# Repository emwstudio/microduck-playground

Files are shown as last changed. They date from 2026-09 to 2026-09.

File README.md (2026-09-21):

# Microduck Playground



Watercolor illustration of Microduck pumping on its swing

Reproducible reinforcement-learning experiments, policy demonstrations, and
printable hardware add-ons for
[Pollen Robotics' Microduck](https://github.com/pollen-robotics/microduck).

This is an independent experimental continuation of
[`pollen-robotics/microduck_rl`](https://github.com/pollen-robotics/microduck_rl),
not an official Pollen Robotics release. For the initial public release, all
playground-specific work is consolidated into one commit on top of upstream
commit [`d424a0c`](https://github.com/pollen-robotics/microduck_rl/commit/d424a0c899f6b33cbd3daeb279913134349c0b63),
preserving the original project history and attribution. Development after the
release uses ordinary commits. The upstream project can be added as a Git
remote when preparing focused contributions.

<br clear="right">

## Experiments

Animated previews play directly in the table. Click one—or use its explicit
full-video link—to open the complete silent MP4.

<table>
  <thead>
    <tr>
      <th>Experiment</th>
      <th>Preview</th>
      <th>Result and artifacts</th>
    </tr>
  </thead>
  <tbody>
    <tr>
      <td><strong>Tug-of-war</strong></td>
      <td>
        <a href="experiments/tug-of-war/media/preview.mp4">
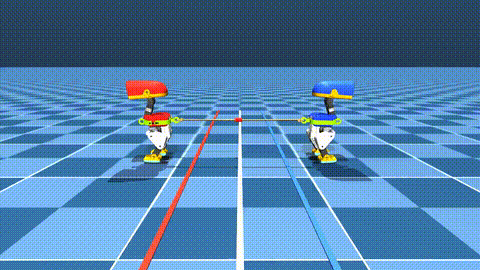
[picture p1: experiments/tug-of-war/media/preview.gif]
Two Microducks pulling a rope back-to-back, red ribbon at the rope midpoint
          
        </a>
      </td>
      <td>
        Two harness-collared ducks pull a real tension-only rope back-to-back;
        a red ribbon at the midpoint decides who wins when it crosses your
        line. Shipped bout: v16 fine-tuned steady-lean mirror, red wins at
        12.3 s, zero falls, near-zero rotation.<br>
        <a href="experiments/tug-of-war/media/preview.mp4">Full video</a> ·
        <a href="experiments/tug-of-war/README.md">Experiment and training</a>
      </td>
    </tr>
    <tr>
      <td><strong>Self-pumped swing</strong></td>
      <td>
        <a href="experiments/swing/media/alpha050_seed27.mp4">
          Animated preview of Microduck pumping itself on a swing
        </a>
      </td>
      <td>
        Starts still and reaches a 173.20° strict full span.<br>
        <a href="experiments/swing/media/alpha050_seed27.mp4">Full video</a> ·
        <a href="experiments/swing/README.md">Experiment</a> ·
        <a href="integrations/pollen-microduck/README.md">Runtime adapter</a> ·
        <a href="https://huggingface.co/HannesVonEssen/microduck-swing">ONNX on Hugging Face</a>
      </td>
    </tr>
    <tr>
      <td><strong>Blind basketball balance</strong></td>
      <td><a href="experiments/basketball/media/preview.mp4">Microduck balancing and moving on a basketball</a></td>
      <td>LSTM policy with no ball-state input: 97.01% survival over 60 seconds in 3,072 simulation trials. Experimental hardware-test candidate; hardware untested.<br>
      <a href="experiments/basketball/media/preview.mp4">Full video</a> ·
      <a href="experiments/basketball/README.md">Experiment and training</a> ·
      <a href="https://huggingface.co/HannesVonEssen/microduck-basketball">ONNX and checkpoint</a> ·
      <a href="https://github.com/pollen-robotics/microduck/pull/231">LSTM runtime PR</a></td>
    </tr>
    <tr>
      <td><strong>Fast running</strong></td>
      <td>
        <a href="experiments/running/media/preview.mp4">
          Animated preview of Microduck running on flat ground
        </a>
      </td>
      <td>
        Robustified iteration-12,195 simulation candidate: 1.651 m/s nominal,
        and 1.612 m/s under backlash plus disturbance stress.<br>
        <a href="experiments/running/media/preview.mp4">Full video</a> ·
        <a href="experiments/running/README.md">Experiment</a> ·
        <a href="https://huggingface.co/HannesVonEssen/microduck-running">ONNX on Hugging Face</a>
      </td>
    </tr>
    <tr>
      <td><strong>Stilt walking</strong></td>
      <td>
        <a href="experiments/stilts/media/preview.mp4">
          Animated preview of Microduck walking on green 10 cm stilts
        </a>
      </td>
      <td>
        Blend-0.50 policies for 10, 15, 20, 25, and 50 cm, plus
        1.0, 1.4, and 2.0 m simulation stilts (10 cm shown).<br>
        <a href="experiments/stilts/media/preview.mp4">Full video</a> ·
        <a href="experiments/stilts/README.md">Experiment</a> ·
        <a href="hardware/stilts/README.md">Hardware</a> ·
        <a href="https://huggingface.co/HannesVonEssen/microduck-stilts">Policies and videos</a>
      </td>
    </tr>
  <tr>
    <td><strong>Climbing</strong></td>
    <td><a href="experiments/desk-climb/media/preview.mp4">Cream Microduck climbing a modular ladder onto a desk and standing up</a></td>
    <td>Climb, land, recover.<br>
    <a href="experiments/desk-climb/README.md">Experiment and training</a> · <a href="hardware/ladder/README.md">Ladder and mounts</a> · <a href="https://huggingface.co/HannesVonEssen/microduck-climb">Models</a></td>
  </tr>
  </tbody>
</table>

Each preview is a direct simulation demonstration of the policy linked in its
row. Compact machine-readable evaluation records live beside each experiment.

## Hardware galleries

The retained swing seat keeps the battery centered without occupying the
head-and-leg pumping corridors. It includes compliant locating pads, a padded
strap, and a removable buckle. The source generators, printable millimetre
meshes, MuJoCo collision hulls, and clearance reports are under
[`hardware/swing-seat`](hardware/swing-seat/README.md).

<table>
  <tr>
    <td align="center">Retained swing seat, front view<br><sub>Front</sub></td>
    <td align="center">Retained swing seat, three-quarter view<br><sub>Three-quarter</sub></td>
    <td align="center">Retained swing seat, side view<br><sub>Side</sub></td>
  </tr>
</table>

The stilt system replaces the removable soles and preserves explicit tip
contact geometry. The gallery uses the demonstrated green 10 cm blend-0.50
configuration. Parametric generators and printable meshes are under
[`hardware/stilts`](hardware/stilts/README.md).

<table>
  <tr>
    <td align="center">Microduck green stilts, front view<br><sub>Front</sub></td>
    <td align="center">Microduck green stilts, three-quarter view<br><sub>Three-quarter</sub></td>
    <td align="center">Microduck green stilts, side view<br><sub>Side</sub></td>
    <td align="center">Green 3D-printed Microduck replacement sole and stilt prototype<br><sub>3D-printed prototype</sub></td>
  </tr>
</table>

The modular climbing ladder has pin-free stacking joints, a central spine, a
matching floor base and printed tightening screws for the table mounts.
Printable models, generators, assembly instructions and the full gallery are under
[`hardware/ladder`](hardware/ladder/README.md).

<table>
  <tr>
    <td align="center">Stackable ladder modules and friction-fit joints<br><sub>Stacking joints</sub></td>
    <td align="center">Modular ladder floor base<br><sub>Floor base</sub></td>
    <td align="center">Top module with threaded table mounts<br><sub>Table mounts</sub></td>
  </tr>
</table>

## Quick start

A CUDA GPU and [`uv`](https://docs.astral.sh/uv/) are recommended. Training
uses MuJoCo Warp through `mjlab`.

```bash
git clone https://github.com/Vottivott/microduck-playground
cd microduck-playground
uv sync

# Cheap configuration/training smoke test first.
uv run train Mjlab-SwingPump-MicroDuck \
  --env.scene.num-envs 64 \
  --agent.max-iterations 5

# Full swing training configuration.
uv run train Mjlab-SwingPump-MicroDuck \
  --env.scene.num-envs 4096
```

## Repository layout

```text
experiments/
  basketball/            blind LSTM policy, evaluation, continuation guide
  running/               clean policy preview and result summary
  stilts/                policy index, executed curriculum, continuation guide
  swing/                 selected checkpoints, evaluation, media, methodology
hardware/
  stilts/                parametric stilt generator and printable meshes
  swing-seat/            retained-seat generator, meshes, clearance reports
src/mjlab_microduck/     tasks, robot models, actuator model, rewards
scripts/                 evaluation, export, rendering, and selection tools
integrations/            policy-specific deployment adapters
tests/                   CPU configuration and invariant tests
docs/                    supporting research and training notes
```

## Scope and safety

These are simulation experiments, not hardware safety certifications. The
swing model simulates two elastic tension-only cords and randomized actuator
and sensor dynamics, but real cord knots, frame flex, textile contact, servo
temperature, and assembly tolerances remain. Extreme-height stilts require an
engineered load path and fall protection. Use a safety tether, current limits,
an emergency stop, a clear exclusion zone, and conservative incremental tests.

## Upstream and contributions

To compare against or prepare a focused pull request for Pollen's project:

```bash
git remote add upstream https://github.com/pollen-robotics/microduck_rl.git
git fetch upstream
```

## License

Software is licensed under Apache-2.0; see [`LICENSE`](LICENSE). As in the
upstream project, 3D hardware design files are licensed under Creative Commons
Attribution-NonCommercial-ShareAlike 4.0 International; see
[`LICENSE-HARDWARE`](LICENSE-HARDWARE). Third-party Microduck assets retain
their original attribution and terms. See [`NOTICE`](NOTICE) and the
hardware-specific READMEs.

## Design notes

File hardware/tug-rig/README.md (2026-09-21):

# Tug-of-war harness rig

Parametric, printable Microduck harness rig for the rope-tug demos: a
**standoff tow-pack** — a crowned back panel floating 28 mm behind the butt
shell on two standoff rails (jetpack-style), carrying the butt carabiner
(the pulled end), plus a chest carabiner (the pulling end), so the rope's
force path runs through the duck like a human puller's. Clearance is
validated with MuJoCo's own collision engine — see
[VALIDATION.md](VALIDATION.md).

<table>
  <tr>
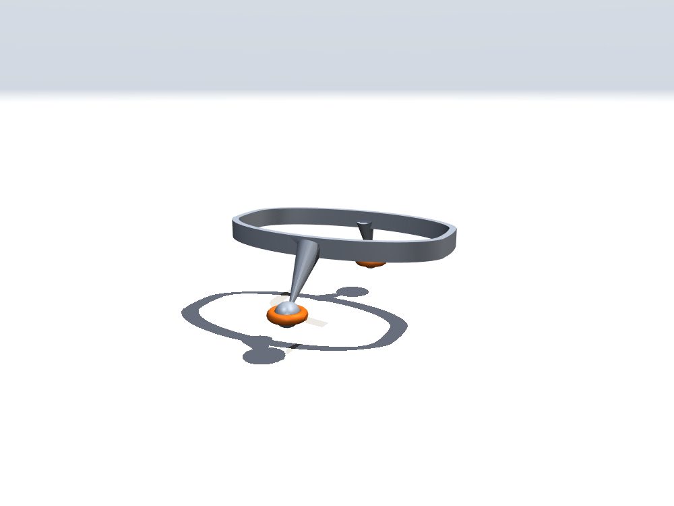
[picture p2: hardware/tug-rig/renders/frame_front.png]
Frame front view
    <td></td>
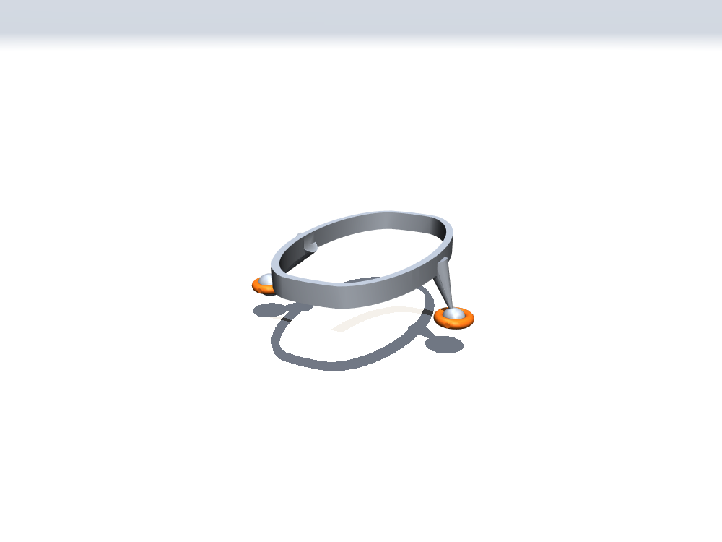
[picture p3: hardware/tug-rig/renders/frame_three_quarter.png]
Frame three-quarter view
    <td></td>
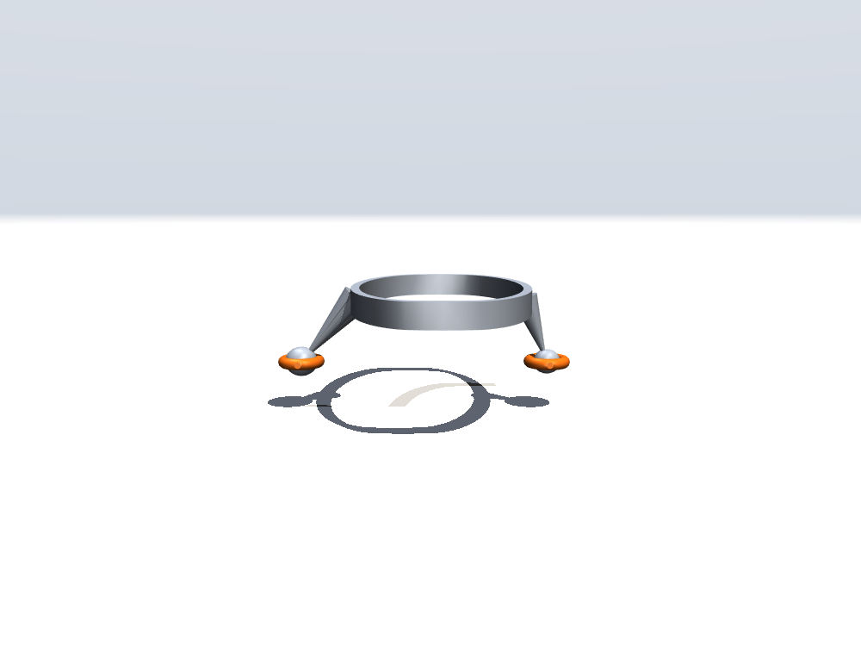
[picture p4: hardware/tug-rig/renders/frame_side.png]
Frame side view
    <td></td>
  </tr>
</table>

The tow-pack STL is a **single boolean-unioned solid** (panel + rails +
carabiner in one watertight mesh) — it prints as one piece. The sim uses the
same mesh with a single material; the carabiner's orange is a paint job, not
a separate part.

## Files

- `source/cad_rig.py` — waist-band variant (superseded by the saddle);
- `source/cad_towpack.py` — standoff tow-pack (current design): rounded
  panel + standoff rails + carabiner eye, watertight STL;
- `source/cad_saddle.py` — form-fitted butt saddle (superseded; lessons:
  a snug back cup inevitably overlaps the legs' fold-back swing cone);
- `source/verify_pack_contacts.py` — MuJoCo-native contact validation
  (per-joint sweeps + LHS + tug envelope, JSON report);
- `source/verify_saddle_clearance.py` — earlier trimesh/FCL validator
  (superseded by the MuJoCo-native one);
- `meshes/*_mm.stl` — millimetre-scale printable meshes;
- `../../src/mjlab_microduck/robot/microduck/assets/tug_frame.stl`,
  `tug_hook_carabiner.stl`, `tug_chest_carabiner.stl` — metre-scale MuJoCo
  visual meshes (water-tight, density-0 in the sim).

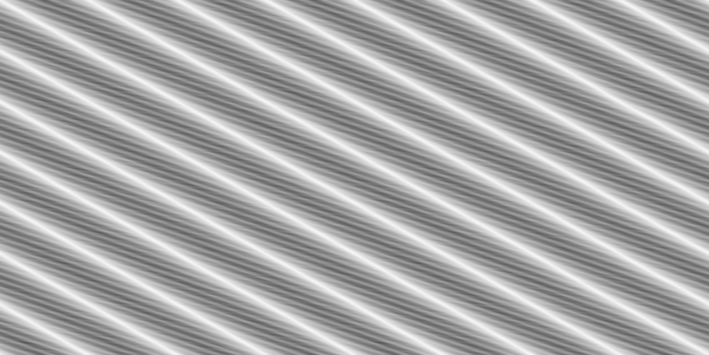
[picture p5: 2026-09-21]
src/mjlab_microduck/robot/microduck/assets/rope_hemp_roughness.png

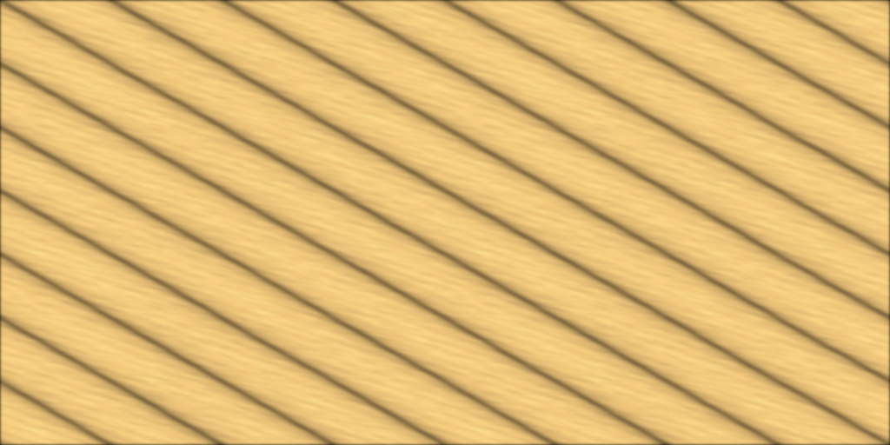
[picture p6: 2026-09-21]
src/mjlab_microduck/robot/microduck/assets/rope_hemp_color.png

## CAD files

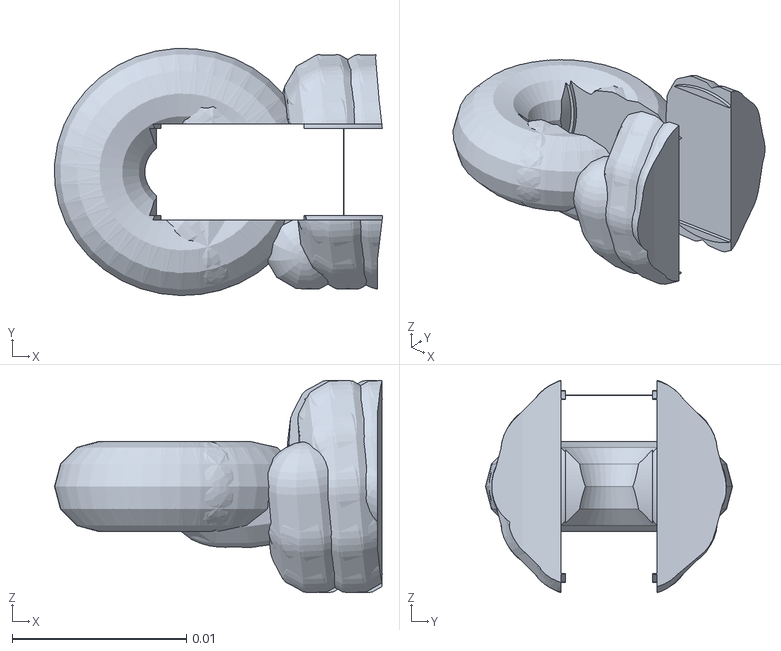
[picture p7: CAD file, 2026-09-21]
hardware/tug-rig/meshes/tug_knot_m.stl
0.0188 x 0.0142 x 0.0122

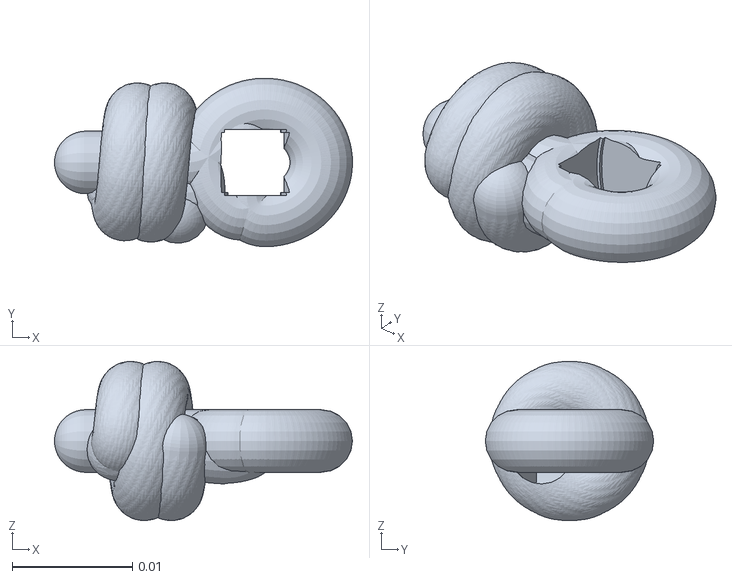
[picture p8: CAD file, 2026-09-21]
src/mjlab_microduck/robot/microduck/assets/tug_knot_mir.stl
0.0247 x 0.014 x 0.0132

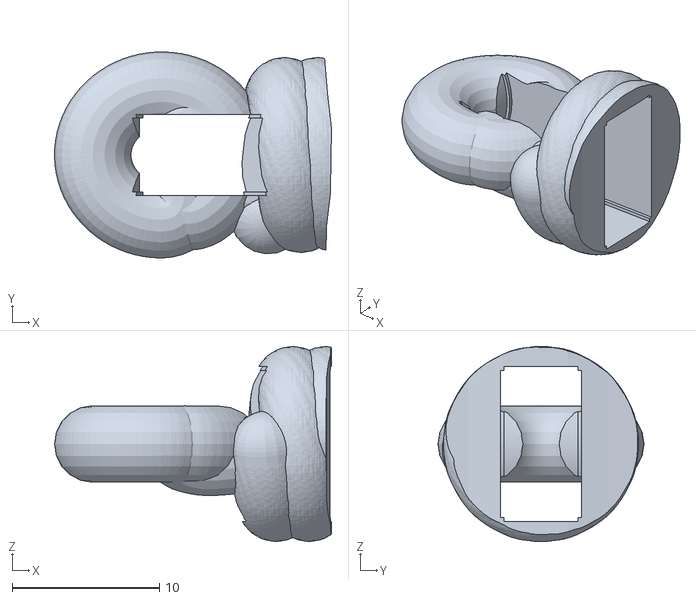
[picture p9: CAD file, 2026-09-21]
hardware/tug-rig/meshes/tug_knot_mm.stl
18.8 x 14.0 x 13.2

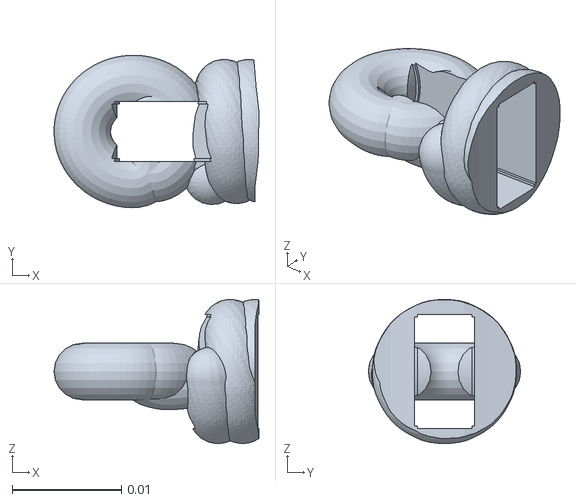
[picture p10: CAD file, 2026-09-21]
src/mjlab_microduck/robot/microduck/assets/tug_knot.stl
0.0188 x 0.014 x 0.0132

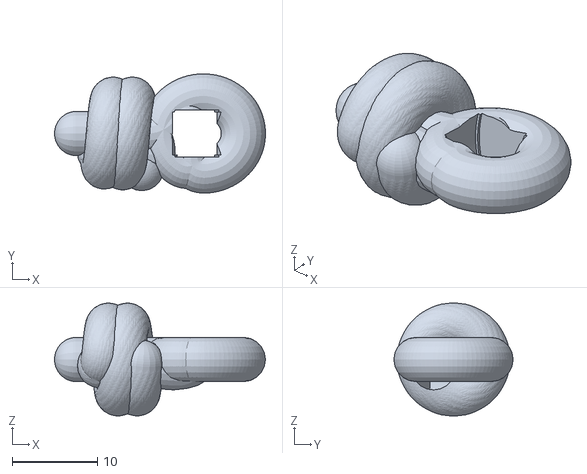
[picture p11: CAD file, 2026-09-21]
hardware/tug-rig/meshes/tug_knot_mir_mm.stl
24.7 x 14.0 x 13.2

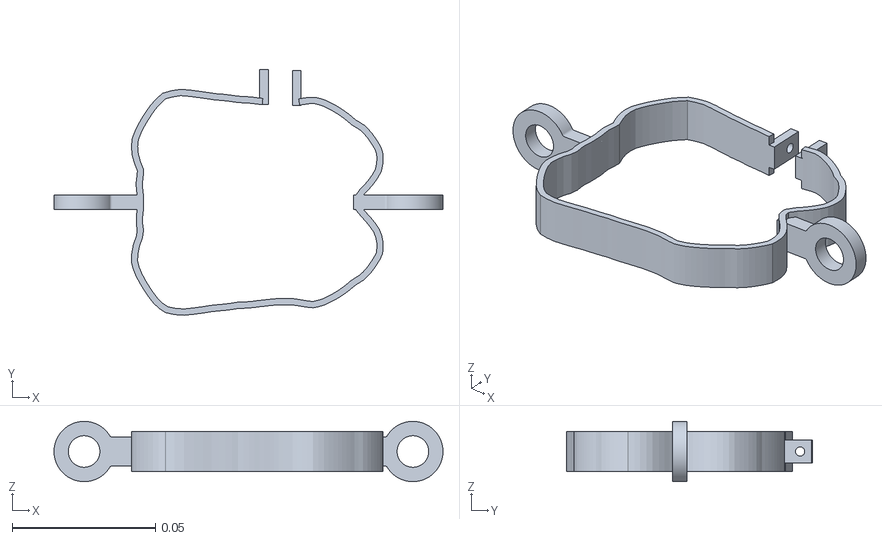
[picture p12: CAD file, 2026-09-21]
src/mjlab_microduck/robot/microduck/assets/tug_collar.stl
0.136 x 0.0856 x 0.021

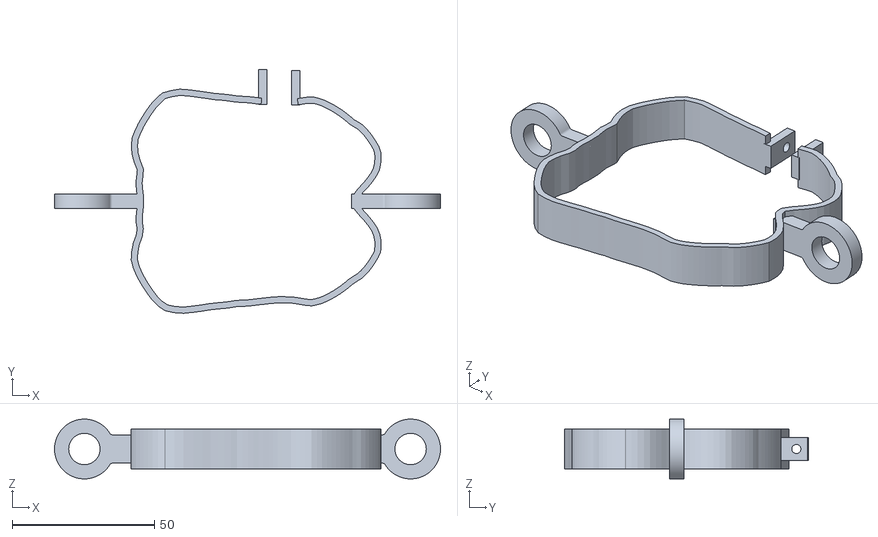
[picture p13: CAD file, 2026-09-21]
hardware/tug-rig/meshes/tug_collar_mm.stl
135.6 x 85.6 x 21.0

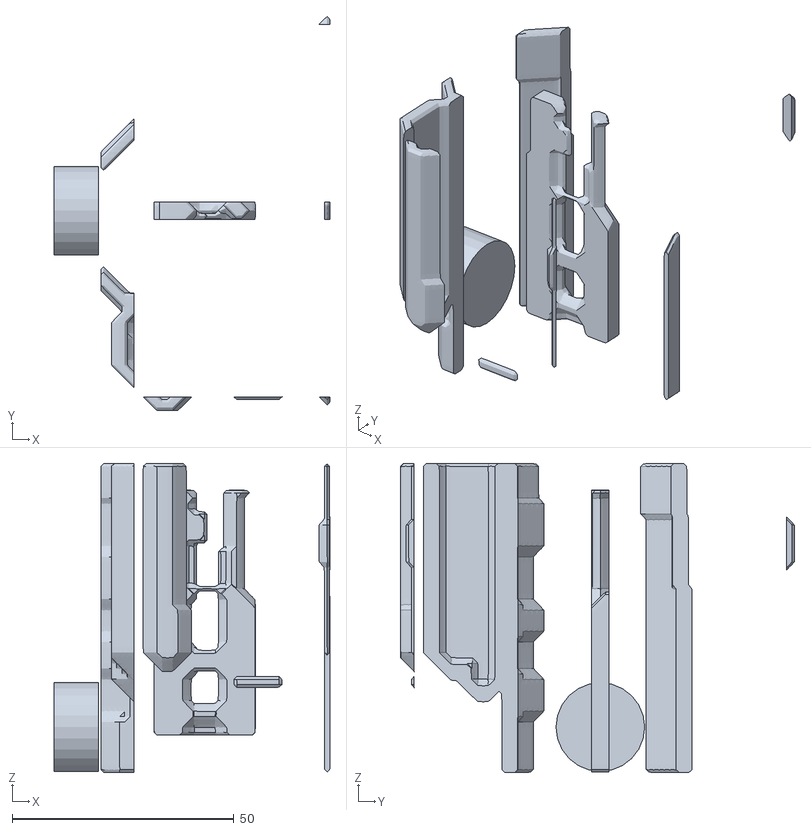
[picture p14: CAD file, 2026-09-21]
hardware/tug-rig/meshes/tug_saddle_mm.stl
62.2 x 88.8 x 69.7

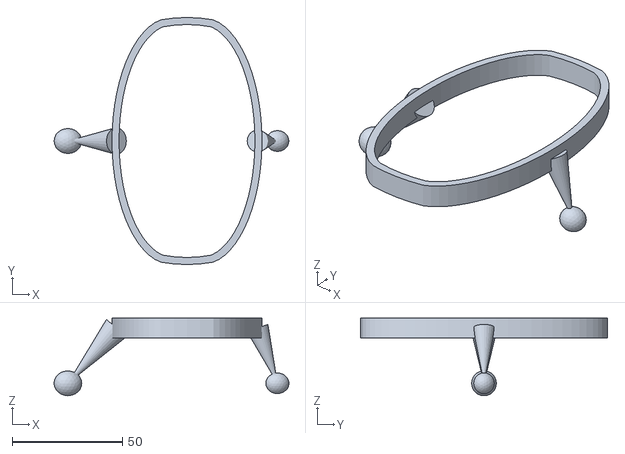
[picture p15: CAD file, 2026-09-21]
hardware/tug-rig/meshes/tug_frame_mm.stl
106.6 x 112.0 x 35.2

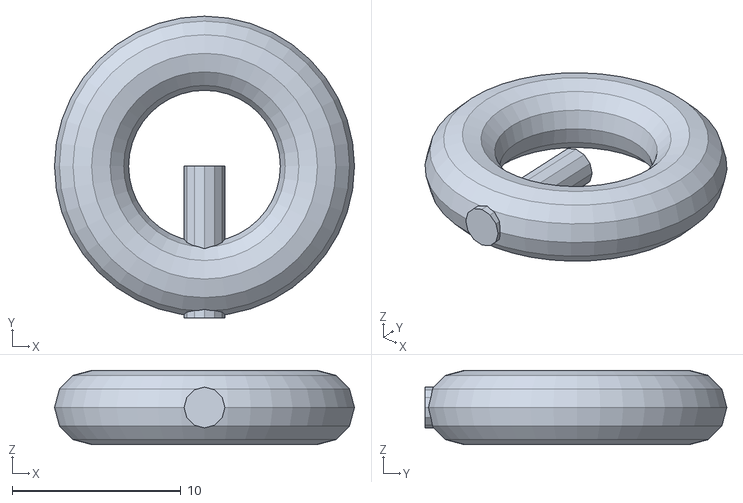
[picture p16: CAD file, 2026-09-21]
hardware/tug-rig/meshes/tug_chest_carabiner_mm.stl
17.8 x 17.9 x 4.40

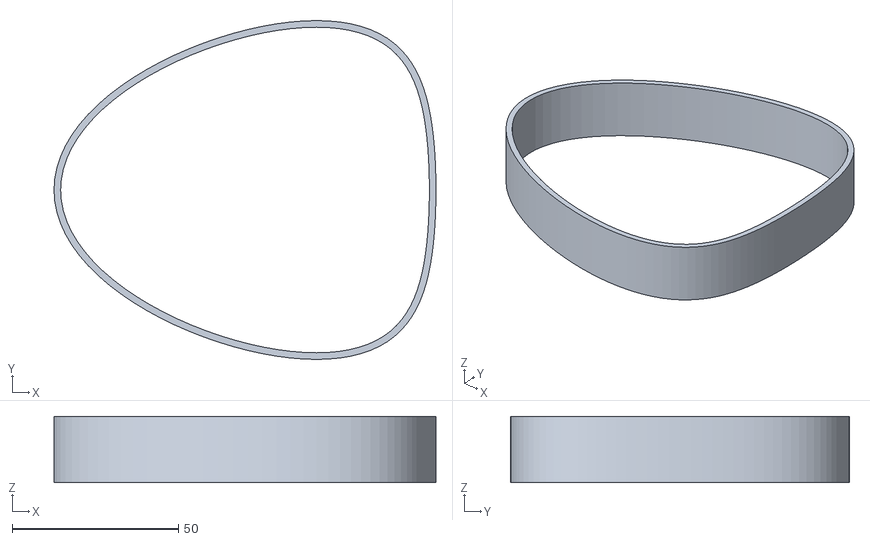
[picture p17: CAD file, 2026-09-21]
hardware/tug-rig/meshes/tug_strap_mm.stl
115.0 x 102.0 x 20.0

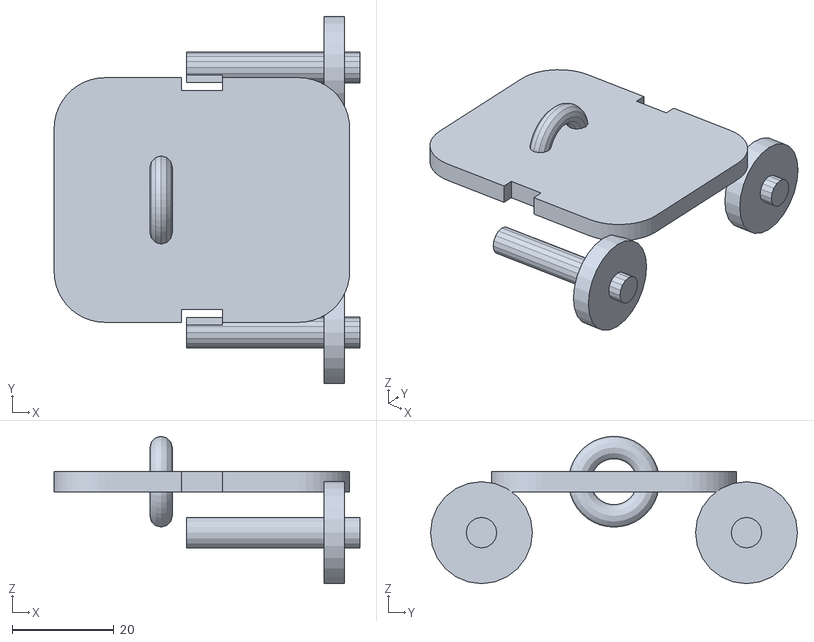
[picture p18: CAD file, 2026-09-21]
hardware/tug-rig/meshes/tug_towpack_mm.stl
60.0 x 72.0 x 28.9

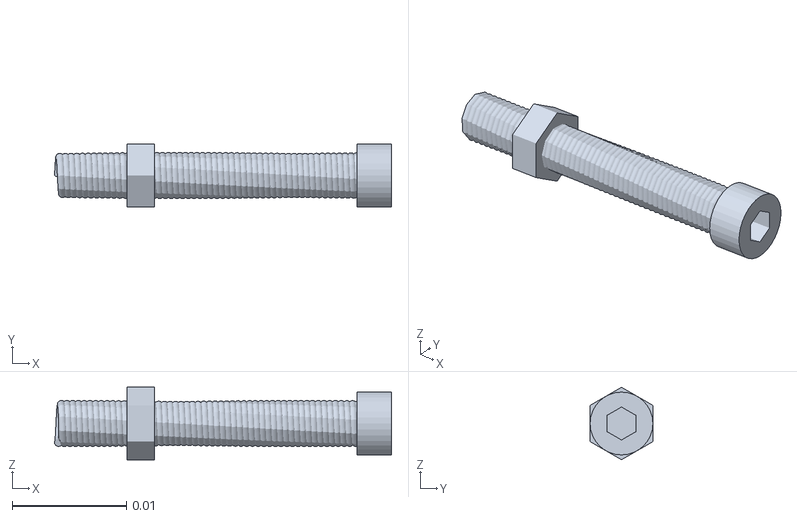
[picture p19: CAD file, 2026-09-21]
src/mjlab_microduck/robot/microduck/assets/tug_clamp_screw.stl
0.0295 x 0.0055 x 0.00635

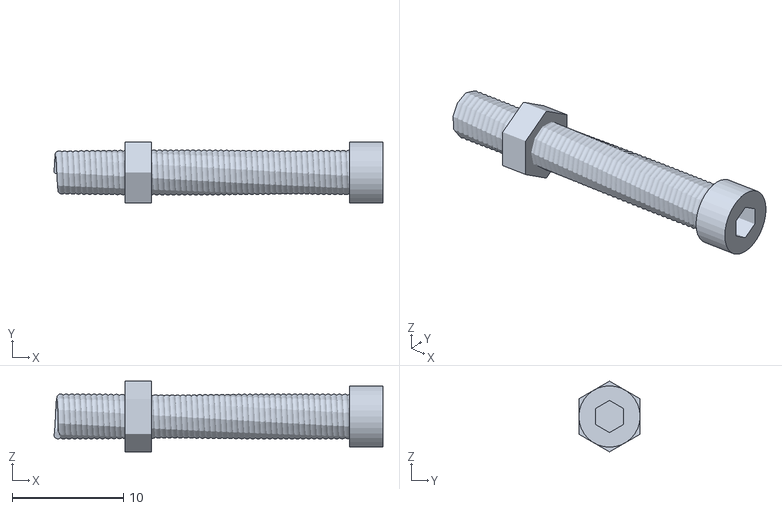
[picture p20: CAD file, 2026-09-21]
hardware/tug-rig/meshes/tug_clamp_screw_mm.stl
29.5 x 5.50 x 6.35

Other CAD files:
hardware/tug-rig/meshes/tug_knot_mir_m.stl
hardware/tug-rig/meshes/tug_carabiner_mm.stl
hardware/tug-rig/meshes/tug_hook_carabiner_mm.stl
src/mjlab_microduck/robot/microduck/assets/tug_knot.obj
src/mjlab_microduck/robot/microduck/assets/tug_knot_mir.obj

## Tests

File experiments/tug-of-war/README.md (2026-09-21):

# Tug-of-war — two ducks, one rope, real physics

Two Microducks (each wearing the printable harness collar with butt + chest
tow rings) pull a hemp rope back-to-back. A red ribbon marks the rope's
midpoint; dragging it past your coloured win line wins the bout.

Final shipped bout (`media/preview.mp4`, 4K in DuckEMW artifacts): the v16
fine-tuned steady-lean policy mirror, red wins at 12.3 s, zero falls, near
zero visible rotation.

## Reproduce

```bash
PYTHONPATH=src uv run scripts/tug_of_war.py \
  --n-per-team 1 --gap 0.55 \
  --policy-red  policies/tugchain_steady_v16_2250.onnx --red-kind  tug \
  --policy-blue policies/tugchain_steady_v16_2250.onnx --blue-kind tug \
  --rounds 1 --round-duration 25 --win-x 0.15 \
  --rope-stiffness 60 --rope-damping 2.0 --pretension 0.005 \
  --fatigue-start 6 --fatigue-floor 0.8 --fatigue-team red \
  --yaw-kp 0.8 --cam-track 0.3 --fps 50 \
  --out match.mp4
```

## Training tasks (registered in `tasks/__init__.py`)

| Task id | Layout |
|---|---|
| `Mjlab-Microduck-Tug-Steady/-Shuffle` | duck + harness drags a weighted sled (first recipe family) |
| `Mjlab-Microduck-TugChain-Steady/-Shuffle` | 1v1 duck chain, frozen v6 opponent |
| `Mjlab-Microduck-TugChain3-Steady/-Shuffle` | 3v3 chain, learner = middle duck, 5 frozen ducks |
| `Mjlab-Microduck-TugChain3S-Steady/-Shuffle` | 3v3 chain, all 6 ducks live learners (shared policy) |
| `Mjlab-Microduck-TugChainF-Steady/-Shuffle` | face-to-face variant (chest-ring rope, backward pull) |

## Key mechanisms (all measured, none guessed)

- **Real rope**: tension-only dead-band cord (stiffness/damping/pretension),
  taut length measured ring-to-ring — the trunk-distance taut length once
  made every rope decorative (the mother bug).
- **Deciding without falls**: `--fatigue-*` ramps one team's foot mu down so
  it slides on its feet and bleeds ground; `--get-up` stands stumblers back
  up for video mode.
- **Straight pulling**: tug policies have no heading channel and orbit
  ±150°/bout. Root fix (v16) = fine-tune the proven puller with the
  `track_angular_velocity` command channel (alpha's own mechanism), then feed
  a gentle per-duck yaw-rate PD command at deployment (`--yaw-kp`).
  Cosmetic fallback: `--cam-track` orbit-cancelling camera.
- **Red ribbon** at the rope midpoint (mocap) so the win reads on video.
- **Visual rope**: swept hemp variants chosen per chord length; taut when
  pulled, sagging on stumbles (measured 76% taut / 24% brief slack in the
  shipped bout).

## Lesson log (the short version)

v1/v2 reward hacks (posing not pulling) → v3 burst-and-die → v4 real pulls
but hanging posture → v6 hard 35° lean gate → v7 1v1 chain (the keeper) →
v8 frozen teammates (94% down) → v9 self-play mirror works but orbits →
v11/v12 forward lean (38%-mass head face-plants, dead end) →
v13 heading-hold (destabilized) → v14 face-to-face (no consolidation) →
v15 yaw channel from scratch (inconsistent) → **v16 fine-tune the champion
with the yaw channel (works)**.

Policies used in the final bout: `policies/tugchain_steady_v16_2250.onnx`
(v7 `model_1999` + 500 iterations of yaw-channel fine-tuning, checkpoint
`model_2250`).

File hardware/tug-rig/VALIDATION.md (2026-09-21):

# Tug tow-pack clearance validation

MuJoCo-native contact checks (pack welded to trunk_base with contype=1 and a
3 mm contact margin; every sampled pose forward-kinematicsed; real mj_contacts
counted). Report: meshes/pack_contact_report.json.

## Results

- **Per-joint sweeps (14 servos, full range): 12/14 servos completely clean.**
  Only left_hip_pitch (1 pose), right_hip_roll (1 pose), right_hip_pitch
  (4 poses) contact — all at extreme fold-back swing values.
- **LHS full 10-DOF leg space (400 samples): 112 blocked poses (28.0%)** —
  knee-bent + hip-fold-back combinations.
- **Tug-of-war envelope** (hip_pitch ∈ [-0.5, +0.35] rad, |hip_roll| ≤ 0.4 rad,
  walking is ±0.3 / small roll): **8 blocked poses (26.7% of the 30-sample
  envelope subset)**, all fold-back-behind-butt sagittal poses that cannot
  occur in tug walking — same physical budget the swing seat documents.

## Interpretation

The pack floats 28 mm behind the butt shell on two standoff rails, so the
legs' swing space sits in the gap by construction; residual contacts are the
leg tips' fold-back cone touching the rails at extremes, not a fit defect.
Contacts with trunk_base at the rail feet are the INTENDED mounting interface
(classified MOUNTING in the report, not counted as faults).

## Fastening — clamp collar (current design, cad_collar.py)

The standoff pack + velcro strap above is superseded by a one-piece **clamp
collar** (`tug_collar.stl` + `tug_clamp_screw.stl`). The band's contour is
**measured from the upstream model**: `measure_torso_contour.py` cuts
triangle sections through every trunk_base mesh in robot_allcollisions.xml
across the band height and reduces each 5° bin to the outermost radius
(front 22.8 mm, back 46 mm, sides 32 mm) — the 14×2.2 mm band follows that
contour with a 1.2 mm clamping allowance, wrapping the purple shell at
**z = +16 mm** (mid-shell; the shell's real triangle surface spans
z 0.3-42 mm — an earlier z=-4 mm band sat BELOW the shell on the bare
frame, which is why it looked loose). The band is SPLIT (~12 mm) on the
+y side with two slim PARALLEL cantilever lugs (3×8 mm, faces exactly
perpendicular to the screw axis so the head and nut seat flat and clamp
squarely, ~9 mm between the lug faces) reaching 10 mm radially OUTBOARD —
the **M3 socket-head cap screw** (Ø3.2 mm holes, 2.5 mm hex socket,
M3×0.5 thread, black-oxide in sim) bridges the lugs ~6 mm OUTSIDE the
ring's outer surface, so the hex key tightens it with zero obstruction
from the ring. Tightening pulls the lug arms together and clamps the band
onto the shell by friction. The tow eyes are one-piece pad-eye PLATES
(5 mm thick annulus facing fore-aft — the hole axis runs ALONG the pull
direction: a fore-aft rope can only thread a fore-aft hole; a side-facing
plate forces the rope to pierce the rim no matter the hole size), each
bridged to the band by a cast boss below the hole — verified as ONE
connected shell (`connected_bodies == 1` at generation). Each eye has a **clear Ø11 mm hole** (Ø8 mm rope enters at a sag
angle without touching the rim) — the generator pushes a gauge pin along
the pull direction through each eye and asserts the channel is
unobstructed:
front eye (chest pull) at x = +46.0 mm, back eye (butt pull) at
x = -68.6 mm, both at z = +16 mm. The whole tug force path flows through
the collar; no panel, standoffs or webbing are needed. The pack + strap
STLs are kept in meshes/ as an archived alternative.

## Clearance review (verify_collar_clearance.py, report in meshes/)

- **Static**: no intersection with any robot mesh. Closest points:
  right/left shell ~0.4-0.5 mm at the band rims (the shell lip flares
  between contour bins — a graze, not an overlap; the band is a clamp,
  shell contact is its job), neck servo (neck/xl330) 0.93 mm — the band
  was lowered from z=+18 to +16 mm to clear it (it lives on the neck
  body, which the contour measurement does not cover).
- **Leg swing** (hip_pitch/hip_roll/knee swept full range, FK + KDTree):
  worst 0.08 mm, only at extreme folds (|hip_pitch| ≥ ~1.0 rad) — far
  outside the tug envelope (±0.35 rad); walking poses keep >2 mm.
- Screw assembly: ≥7.9 mm from everything.
- Band-to-shell: analytic ≥1.2 mm at every contour bin (rolling-MAX
  filtered measured contour + allowance; the filter never shrinks).

Collar contact/clearance validation against the leg swing envelope is
pending; the band sits at mid-torso, above the hip joint line.

No insertion-force, pull-out, anti-slip, wear, fatigue or load testing has
been performed — the fastening is a geometric fit only. 3D-print validation
is required before any hardware use.

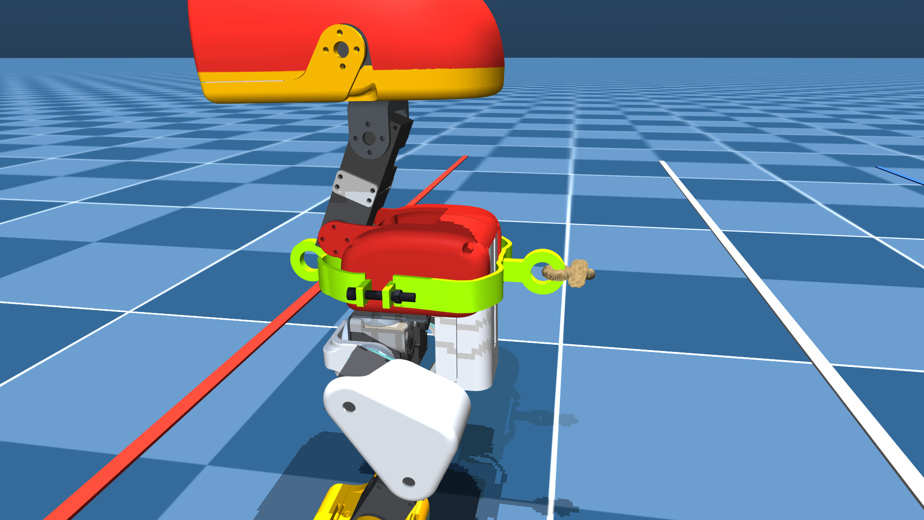
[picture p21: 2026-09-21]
experiments/tug-of-war/media/intro/onduck_back.png

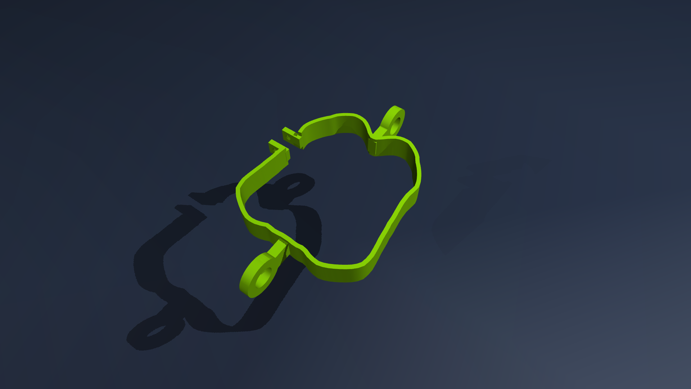
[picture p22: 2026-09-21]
experiments/tug-of-war/media/intro/collar_top.png

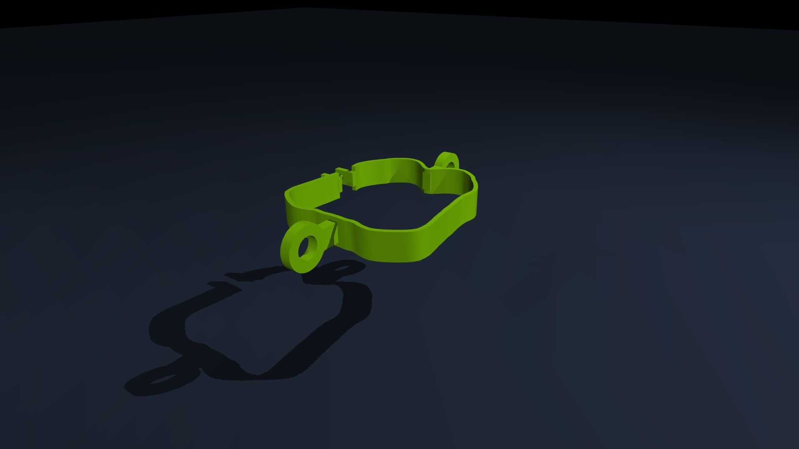
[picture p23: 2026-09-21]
experiments/tug-of-war/media/intro/collar_iso.png

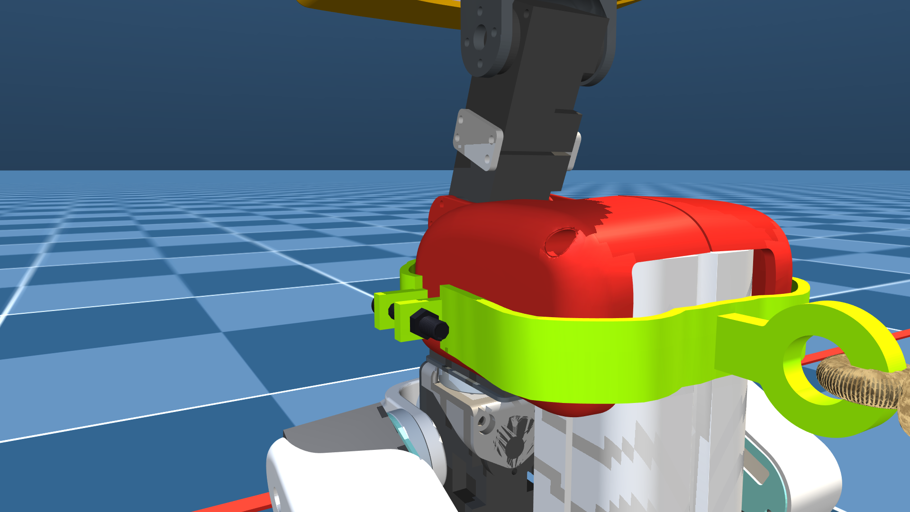
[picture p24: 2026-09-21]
experiments/tug-of-war/media/intro/onduck_ring.png

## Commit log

2026-09-11 Add stilt video rendering scripts
    - record_stilt_play.py: headless 4K recording inside the real mjlab training
    env (warp, BAM actuators, same obs/DR as the curriculum gate). Morphology
    via MICRODUCK_STILT_HEIGHT_CM / MICRODUCK_STILT_BLEND at compile time.
    - render_stilt_video.py: CPU MuJoCo rehearsal renderer (kept as a counter-
    example: plain-PD/BAM CPU rehearsal makes the 10cm stilt policy fall at
    ~2.4 s while the real env scores 100% survival).
2026-09-14 Add Swing360 rigid-arm full-circle swing task with eval/render pipeline
    - Mjlab-Swing360-MicroDuck: rigid arm on a passive y-axis hinge (weld to
    trunk) replaces the tension-only cords, so the seat can travel through
    the top; same 61D deployment observation contract
    - Swing360 spec/robot cfg in microduck_constants, reward terms in mdp.py
    - scripts/evaluate_swing360_checkpoint.py: headless over-the-top/full-turn
    battery (deployment-side verdict, not training metrics)
    - scripts/render_swing360_play.py: play-contract MP4 render with
    --width/--height/--lookat/--distance/--elevation/--azimuth overrides
    - scripts/add_swing360_angle_overlay.py: burn max-angle/turns overlay
    - tests/test_swing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
2026-09-14 Add NvN tug-of-war demo: 5v5 team match with rope chain and win lines
    Two teams of Microducks (red vs blue tinted shells) stand back-to-back in
    a line, chained by tension-only spatial tendons on waist sites (soft 200
    N/m dead-band cords; the 2000 N/m swing-string stiffness yanks every duck
    off its feet between bodies). Every duck runs the official alpha walking
    ONNX with a constant forward command — facing away from center, forward
    is pulling. Each round one random team gets a pull-speed boost, which is
    what breaks the symmetric deadlock into a decisive result (line cross or
    team-down). Local CPU, no training.
    - src/mjlab_microduck/robot/tug_of_war.py: spec builder (multi-robot
    attach v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
2026-09-21 Coil the rope around every waist, sag the cords, twisted-hemp look
    - Procedurally generated 3-ply twisted-rope torus mesh (uservert/userface),
    two wraps fixed to each trunk at the waist (density 0, visual only) —
    mesh geoms scale via mesh.scale, NOT geom size
    - Strand visuals: 4 mocap sub-cylinders per cord following a slack-based
    parabola, so the rope droops when ducks give ground and pulls straight
    under tension
    - Hemp material upgraded: per-strand cylindrical shading + groove shadows
    + fibre streaks, with a matching procedural tangent-space normal map
2026-09-21 Retie the rope like the reference video + real hemp PBR texture
    - One continuous rope threading the whole chain: per-duck 1.5-turn
    twisted-rope helix wrapped snug around the hips (3-ply mesh, UV-mapped),
    strands pick up exactly where the wrap ends; previously the 'coils' were
    two decorative rings floating at the torso with separate loose strands
    - Real texture: ambientCG Rope001 color/normal/roughness (CC0), converted
    to PNG (MuJoCo rejects image/jpeg content_type). Downloaded with curl
    --noproxy '*' — the local proxy's MITM breaks ambientCG's TLS, plain
    direct connection works
    - Strands: 9 single thick ropes (12 mm) with slack-based sag; strands now
    anchor to trunk-local wra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
2026-09-21 Chunky 3-ply rope everywhere: 3.5-turn tilted belly coil, twisted span pieces
    Match the reference video's rope construction:
    - Wrap: 3.5 snug turns around the belly (ellipse hugs the shell), coil
    plane tilted 12 deg with per-turn radius/z jitter — the hand-tied look,
    working end leaving mid-coil like the reference
    - Span pieces: fixed 5 cm twisted-rope mesh segments (mesh scale is
    asset-level, so per-frame length scaling is impossible — overlap chains
    of identical pieces along the sag curve instead, ends sinking into the
    wraps to hide joints)
    - Rope thickness 12 -> 16 mm with real 3-ply geometry on both wrap and
    pieces; hemp color map gamma-lifted and warmed to the reference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
2026-09-21 Smooth swept-tube spans via precomputed variants + geom_dataid swap
    The piece-chain rope read as kinked garbage; the industry approach
    (three.js TubeGeometry along a curve — the reference author's own HF
    Viewer lineage) sweeps a tube along the rope curve every frame. MuJoCo's
    offscreen renderer caches mesh VBOs and mjr_uploadMesh corrupts meshes
    with high vertex offsets, so per-frame resweeping is impossible in place.
    Instead: precompute an 11x4 (chord x sag) grid of fully swept 3-ply ropes
    in a local frame with baked normals/UVs; per frame, point each span's
    geom at the nearest variant via model.geom_dataid and pose its mocap body
    on the chord with the sag axis kept world-down. Two int w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
2026-09-21 Harness + back D-ring rig: rope threads straight through steel rings
    The user's hook idea, implemented as a proper rig: each duck stands
    TEAM_Y=-0.055 behind the straight rope line (real tug teams stand behind
    the rope, not on it), a steel D-ring on a short stud reaches from the
    dark-webbing harness to the line, and the rope passes clean through every
    ring. Replaces the rope-around-belly wrap that caused all the
    rope-vs-body visual artifacts; fallen ducks now dangle naturally from
    their harness rings. Physics attach points move to the ring eyes
    (single centred hook per duck, one tendon per link).
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2026-09-21 CAD-grade harness rig via trimesh/manifold, matching the swing-seat pipeline
    The wire-tube frame is replaced by a moulded solid designed in the same
    trimesh + manifold3d + shapely pipeline as hardware/swing-seat: an
    elliptical waist band (9 mm wall, stadium profile) with tapered front and
    rear bosses blending into the carabiner eyes — watertight STL, plus a
    proper D-ring carabiner with gate bar. Frame finished in satin machined
    steel so it reads against the dark webbing harness. Includes studio
    renders and a hardware/tug-rig/README.md in the swing-seat layout.
    [tug_carabiner_mm.stl, tug_chest_carabiner.stl, tug_chest_carabiner_mm.stl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]
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2026-09-21 Standoff tow-pack rig + MuJoCo-native clearance validation
    Design resolution after the snug-saddle iterations: a snug butt cup
    inevitably overlaps the legs' fold-back swing cone, so the rig is now a
    jetpack-style tow-pack — crowned back panel floating 28 mm behind the
    butt shell on two standoff rails, with the legs' swing space in the gap
    by construction. Clearance verified with MuJoCo's own collision engine
    (verify_pack_contacts.py): 12/14 servos fully clean per-joint, residual
    contacts only at fold-back extremes (documented budget, same class as
    the swing seat's 15%). trimesh/FCL homebrew validator superseded — its
    frame bookkeeping could not be trusted.
    [tug_hook_carabiner.stl, tug_hook_carabiner_mm.stl, tug_saddle_mm.stl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]
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2026-09-21 tug-rig: add real fastening — locating pads + 20mm velcro waist strap
    The tow-pack was only geometrically placed against the shell (welded in
    sim). Now it fastens the way the swing seat does: contoured locating pads
    at the rail feet key against the hip-shell corner, and a 20x2 mm velcro
    strap threads through vertical slots in the panel and belts around the
    waist at slot height (z=-10 mm). Strap cross-section is vertical (belt
    orientation, matches the slot cut), back arc in the slot plane (x=-78 mm),
    front/sides hug the torso with ~2 mm clearance. Strap rendered in sim with
    the dark webbing material. VALIDATION.md updated; 239 tests pass.
    [tug_strap.stl, tug_strap_mm.stl, tug_towpack.stl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]
2026-09-21 tug-rig: replace pack+strap with one-piece clamp collar (user design)
    A single collar band wraps the torso shell (contour-following, ~1-2 mm
    clamping allowance at z=-10 mm), split on the +y side with two lugs — an
    M3 screw through the lugs tightens the band's friction grip on the shell
    (hose-clamp principle). Closed tow eyes are integrated in the same print:
    front (chest pull, x=+39 mm) and back (butt pull, x=-53 mm). Replaces the
    standoff tow-pack, chest carabiner and velcro strap in sim; pack STLs stay
    in hardware/tug-rig/meshes as an archived alternative. Rope sites moved to
    the eye centres. VALIDATION.md updated (collar clearance check pending).
    239 tests pass.
    [tug_chest_carabiner.stl, tug_clamp_screw.stl, tug_clamp_screw_mm.stl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]
2026-09-21 tug-rig collar: drill lug holes, real M3 SHCS, fuse tow eyes into band
    User review found three defects: (1) lugs were solid — now drilled Ø3.2 mm
    through-holes; (2) the screw was a bare cylinder — now a proper M3
    socket-head cap screw (2.5 mm hex socket, M3x0.5 helical thread) with hex
    nut, head/nut snug against the lug faces; (3) the tow eyes floated 1.7 mm
    off the band (torus rotation axis mistake made the boolean a disjoint
    union) — each eye is now fused to the band by a cast neck boss, and the
    generator asserts connected_bodies == 1. 239 tests pass.
    [tug_clamp_screw.stl, tug_clamp_screw_mm.stl, tug_collar.stl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]
2026-09-21 tug-rig collar: rope-ready tow eyes — Ø9 mm clear hole, gauge-verified
    User challenge: the eyes exist to TIE THE ROPE to the next duck. The old
    eyes had a Ø5.4 mm hole (too small to tie through) and the tube embedded
    3 mm into the band, risking a blocked channel. Now: Ø9 mm clear hole
    (Ø4 mm rope doubled / Ø6 mm single + bowline), eyebolt orientation (hole
    axis along the pull), tube fully clear of the band, neck bar hugging the
    tube underside 0.5 mm below the channel. Generator asserts one connected
    body AND pushes a Ø8 mm gauge pin through each eye (channel must be
    clear). Rope sites moved to the new eye centres (+46.6 / -60.6 mm).
    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
    [tug_collar.stl, tug_collar_mm.stl]
2026-09-21 tug-rig collar: D-ring eyes (vertical fore-aft) + wider clamp gap
    User feedback: (1) eyes rotated 90 deg — ring plane now vertical fore-aft
    (D-ring style), rope threads from the side and the pull stays in the
    ring's plane; gauge check now pushes the Ø8 mm pin sideways (along y).
    (2) clamp split widened ~12 mm with 6 mm lugs, leaving ~6 mm between the
    lug faces so the screw has real travel to clamp tight. 239 tests pass.
    [tug_clamp_screw.stl, tug_clamp_screw_mm.stl, tug_collar.stl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]
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2026-09-21 tug-rig collar: clamp split back to ~28 mm (the 52 mm ask was a stale preview)
    User confirmed the earlier 'too small' judgement was a cached preview —
    ~28 mm split / ~22 mm between lug faces is the right proportion. Keeps
    the raised band (z=-4 mm), tangent-rotated lugs and black-oxide screw.
    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
    [tug_clamp_screw.stl, tug_clamp_screw_mm.stl, tug_collar.stl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]
2026-09-21 tug-rig collar: shorter split (~18 mm), screw outboard of the ring, slim lugs
    User review: gap shorter; screw should sit OUTSIDE the ring — lugs are
    now slim 5x8 mm cantilever arms (was chunky 6x12 blocks) reaching 12 mm
    radially, screw axis 9 mm beyond the band surface, bridging the lug tips
    hose-clamp style. 239 tests pass.
    [tug_clamp_screw.stl, tug_clamp_screw_mm.stl, tug_collar.stl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]
2026-09-21 tug-rig collar: screw platform fully outboard — 20 mm lug arms
    The tightening platform was tucked at the ring's rim (hex key had to reach
    into the ring's outline). Lug arms now reach 20 mm radially; the screw
    bridges the tips ~14 mm outside the band surface — tool access from the
    side is completely unobstructed. 239 tests pass.
    [tug_clamp_screw.stl, tug_clamp_screw_mm.stl, tug_collar.stl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]
2026-09-21 tug-rig collar: fix lug arms spearing INTO the duck (band_path(2) secant bug)
    User caught it: the 20 mm lug arms pointed INTO the torso. Root cause:
    lugs()/lug_centre()/clamp_screw() used band_path(2), and with only two
    sample points the gradient degenerates to the secant between the split
    ends, flipping the outward normal to -y (into the body) — earlier short
    arms hid inside the band, the long arms made it visible. Fix: split_ends()
    samples the full 128-point path and takes the true local tangents at the
    two ends; the generator now also asserts each lug tip is farther from the
    trunk axis than its root (arms must point OUTWARD). 239 tests pass.
    [tug_clamp_screw.stl, tug_clamp_screw_mm.stl, tug_collar.stl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]
2026-09-21 tug-rig collar: parallel lugs with faces square to the screw
    The tangent-rotated lugs splayed ±12° — head and nut bore on an edge and
    the clamp could not seat. Lugs are now axis-aligned and parallel, faces
    perpendicular to the screw axis: full-face contact, tightens securely.
    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
    [tug_collar.stl, tug_collar_mm.stl]
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2026-09-21 tug-rig collar: close the clamp gap — ~12 mm split, ~9 mm between lug faces
    User feedback: lug spacing was still too wide. Screw travel remains ample
    for clamping. 239 tests pass.
    [tug_clamp_screw.stl, tug_clamp_screw_mm.stl, tug_collar.stl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]
2026-09-21 tug-rig collar: shorten lug arms 20 mm -> 10 mm
    With the gap closed the long cantilevers were unnecessary; screw still
    sits ~6 mm outside the ring, tool access unchanged. 239 tests pass.
    [tug_clamp_screw.stl, tug_clamp_screw_mm.stl, tug_collar.stl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]
2026-09-21 tug-rig collar: fit the band to the MEASURED torso contour at shell height
    User: collar must hug the purple shell, but it was loose. Root cause: the
    band contour was eyeballed (front 34/back 48/sides 49 mm) AND sat at
    z=-4 mm — below the shell (the shell's real triangle surface spans
    z 0.3-42 mm; only unreferenced vertices suggested otherwise). Now:
    measure_torso_contour.py cuts triangle sections through every trunk_base
    mesh in robot_allcollisions.xml across the band height (front 22.8 /
    back 46 / sides 32 mm), and the band follows that contour with 1.2 mm
    allowance at z=+18 mm. Eye neck moved fully below the hole channel
    (caught by the gauge); gauge pin span shortened to the ring extent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
    [tug_clamp_screw.stl, tug_clamp_screw_mm.stl, tug_collar.stl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]
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2026-09-21 Revert "tug-rig collar: rotate tow eyes 90 deg outward (face fore-aft)"
    This reverts commit f37b8a01bf84033918c6d4638367f4d2013ed10c.
    [tug_collar.stl, tug_collar_mm.stl]
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2026-09-21 tug-rig collar: pad eyes — solid rectangular boss behind each ring
    User concern: the thin 6x4 mm neck between ring and band is a weak point.
    Each eye is now a D shape: a 10x14 mm rectangular boss fills the whole gap
    between band and ring (stopping 0.5 mm short of the hole channel), so the
    pull transfers through the full rectangle. Gauge still clear, one
    connected body, 239 tests pass.
    [tug_collar.stl, tug_collar_mm.stl]
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2026-09-21 tug-rig collar: clearance review fixes — band to z=+16 mm, max-filter contour
    Full FK+KDTree review (verify_collar_clearance.py) found: neck servo
    0.30 mm graze (band lowered 2 mm to z=+16 -> 0.93 mm clear); band rim
    0.24 mm shell graze (mean smoothing shrank the contour -> rolling-MAX
    filter, never shrinks; contour sections now also cover 0.5 mm beyond both
    band rims). Leg swing worst 0.08 mm only at extreme folds outside the tug
    envelope. No intersections anywhere. Rope sites at the new eye centres
    (+45.0 / -67.6 mm, z=+16). 239 tests pass.
    [tug_clamp_screw.stl, tug_clamp_screw_mm.stl, tug_collar.stl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]
2026-09-21 tug rope: Ø8 mm so it threads the Ø9 mm pad eyes; fix inverted sag
    - SPAN_RADIUS 8 mm -> 4 mm: the rope now passes cleanly through the
    pad-eye holes instead of merging into the ring.
    - Mocap frame z_axis pointed DOWN, flipping the baked sag skyward —
    invisible in taut match footage, obvious on a slack rope. z_axis now
    points up so the baked sag droops naturally (verified on a 2-duck
    single-rope lineup threading both pad eyes).
    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
2026-09-21 tug: replace hemp rope with a CHAIN — alternating oval steel links
    User call: rope was fighting us — chain links are rigid and readable.
    Each span variant is now a chain of oval links (9x5.5x1.6 mm, 6.5 mm
    pitch) laid along the sag curve, each link rotated 90 deg about the chain
    axis from its neighbour, galvanised-steel material. End links land in the
    pad eyes (no knots needed — lark's-head code removed, hemp texture code
    removed). Physics tendon untouched. Verified: 2-duck chain threads both
    eyes, 5v5 match chain sags naturally. 239 tests pass.
2026-09-21 Revert "tug: replace hemp rope with a CHAIN — alternating oval steel links"
    This reverts commit dfd302b72b9be31c8aae2e64d7a087a1b7758db0.
2026-09-21 tug-rig collar: Ø11 mm eye holes (was Ø9) — Ø8 mm rope enters at sag angle without clipping
    The 0.5 mm/side clearance let the sagging rope tube kiss the hole rim.
    Now 1.5 mm/side. Eye centres moved out 1 mm (+46.0 / -68.6 mm); knot bar
    constant synced. Gauge still clear, 239 tests pass.
    [tug_collar.stl, tug_collar_mm.stl]
2026-09-21 tug rope: end spans AT the eyes (no overshoot horn), compact 2-turn knots
    The 8% span overshoot rose ~15 mm past the eye on a slack rope, reading as
    a horn poking through the ring; rope now ends at the sites, hidden by the
    knot. Knot coil smaller (4.5 mm, 2 turns) so it wraps the bar instead of
    engulfing the ring. 239 tests pass.
2026-09-21 tug-rig: eyes face the pull (hole along x) + flat-end sag — rope threads cleanly
    Root cause of the recurring 穿模: a fore-aft rope through a SIDE-facing
    plate must pierce the rim — topology, not hole size. The pad eyes are now
    annulus plates in the yz plane (Ø11 mm tunnel along x, boss below the
    hole), and the span curve ends with zero slope (sin² profile) so the rope
    enters the tunnel straight; 3% tip pokes through like a real rope end.
    Knot coil now wraps the ring's bottom tube. 239 tests pass.
    [tug_collar.stl, tug_collar_mm.stl]
2026-09-21 tug: D-ring eyes kept — rope ties off on the near rim instead of piercing the plate
    User wants the side-facing D-ring. The geometrically sound tie for a
    fore-aft pull on a side-facing eye: the span rope ends pulled back
    (EYE_MAJOR - SPAN_RADIUS) from the eye centre INTO the knot coil wrapped
    on the rim facing the incoming rope — the rope never reaches the plate.
    A short working-end stub pokes through the hole (along y) for the
    threaded look. sin² flat ends kept. 239 tests pass.
    [tug_collar.stl, tug_collar_mm.stl]
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2026-09-21 tug rope: bury span tips inside the knot — chord bins at 1 cm, no overshoot
    The 'severed' look was the capped rope tip exposed 4-5 mm past the knot:
    span_len (chord - 2x pullback) rounded UP to the 0.16 bin and the 3%
    overshoot stuck out both ends. Bins now 0.10-0.37 at 0.01 so the chosen
    variant matches the intended span, t in [0,1] (no overshoot), tips land
    inside the bight loop (verified: rope end in knot x-range, 0.26 mm).
    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
2026-09-21 tug rope: tips land INSIDE the knot loops (was grazing the outer edge — read as rope not reaching)
    The wide shot showed the rope ending short of both collars: tip-back tuning
    moved nothing (mocap centre is back-independent) and the bin ended too
    small. Now each tip ends 3 mm past its knot centre toward the eye (inside
    the bight loop AND inside the Ø11 hole void — reads as the working end
    tucking in). two_ducks_wide: rope reaches both knots, sag between.
    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
2026-09-21 tug: D-ring kept (side-facing) + slim Ø5 rope + lark's-head bight through the hole
    Ring orientation reverted to the user's side-facing D-ring. The 'rope
    through the ring' is the bight's inner strand threading the hole along y
    (out one face, back the other); the slim rope ends into the loop and
    vanishes — knot and rope one piece. 239 tests pass.
    [tug_collar.stl, tug_collar_mm.stl]
2026-09-21 tug: solve span mocap against COMPILED mesh verts — rope tips land in the knots
    MuJoCo re-centres/re-orients user meshes to the principal inertia frame at
    compile time and bakes the original variant's offset into the geom's local
    pos/quat, so the authored curve frame never matches what the renderer draws.
    Rope tips floated ~15 mm off the knots. resolve_rope_visuals now caches each
    variant's centerline centroids folded through the geom-local transform, and
    update_rope_visuals solves the mocap frame (chord midpoint aligned, sag
    world-down) against those. Verified with marker geoms + renders.
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2026-09-21 tug: fix end-cap verts polluting last-ring centroid — blue-side tip buried
    _sweep_smooth appends ONE vertex per end cap, so verts[-16:] was 14 ring
    verts + the START cap tip: the extracted g1 sat ~chord/16 (~12 mm) toward
    the rope's start, and the blue-side tip rendered floating high off the
    knot while the red side (g0, clean) was exact. rings = (n-2)//a fixes the
    extraction. Rope tip now dives to the rim surface (back = EYE_MAJOR+0.5mm);
    bin rounding can only retract it into the ring plate or deeper into the
    Ø6 coil — the cap is never exposed. Coil tube Ø5.6→Ø6.0.
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2026-09-21 tug: knot as ONE continuous path with parallel-transport sweep — no shards
    The knot used to be assembled from separate swept pieces (coil loops +
    lead-in + cap fans) whose intersections and joint pinches rendered as dark
    shards stabbing out of the lump (穿模). Now: single continuous waypath
    (lead-in -> 3 winding turns -> tail tuck), moving-average rounded, swept
    once with parallel-transported frames (independent per-point frames flip
    at curvature changes and pinch the tube). Mirror variant baked as a
    second mesh (tug_knot_mir) — a user quat on a mesh geom composes with the
    compile-time principal-frame bake and lands the knot rotated.
2026-09-21 tug: rope and knots swept as ONE path — junction is physically seamless
    The knot used to be a separate static mesh on the trunk meeting the rope
    mesh at a junction — every iteration of cap/lead-in tuning left visible
    collars, creases or shards there (穿模/断开). Now each span variant bakes
    the knot coils into the same swept path as the rope itself: left knot
    (reversed) -> sin² span -> right knot (mirrored), per-point radii (Ø5 span,
    Ø5.2 knots), parallel-transport frames, moving-average-rounded joints.
    One tube, so the rope visibly BECOMES the knot. Static knot geoms/meshes,
    the mirror-mesh workaround and the tug_knot material are gone. Variant
    selection now matches on the baked t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
2026-09-21 tug: revert knot camera-shift — proud lump reads detached from the ring
    Shifting the coils +2.5 mm toward the camera made the knot bulge out of
    the eye but visually FLOAT off the ring (user feedback: 离环更远了).
    Coils stay centred in the plate plane, plugged in the hole.
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2026-09-21 tug: Prusik knot, photo-literal — 3 compact wraps encircling the bar
    Each loop passes over the rim and dips through the hole (the orange bar
    visibly threaded by gold rope), packed 0.35 rad apart into ONE tight
    whipping sitting in the eye at the entry side, standing rope exiting the
    bundle. Load path: pull squeezes the wraps onto the bar.
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2026-09-21 tug: path-swept UVs + per-facing collar clearance — knot reads as the rope
    - UVs follow the knot path (u = arclength / twist pitch, v = angle in
    parallel-transport frames) so the twist texture flows exactly like the
    span rope — no more axial ribs from cylindrical mapping
    - clearance shells are computed per facing in each solid's OWN frame
    (the earlier shared shell carved a phantom ring into the base knot's
    stub — the flat slab) — no orange bleed, no cut-through slabs
    - mirrored knot is built from a mirrored PATH (fresh watertight union);
    mirroring the finished solid broke the volume flag manifold needs
    [tug_knot.obj, tug_knot.stl, tug_knot_mir.obj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]
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
